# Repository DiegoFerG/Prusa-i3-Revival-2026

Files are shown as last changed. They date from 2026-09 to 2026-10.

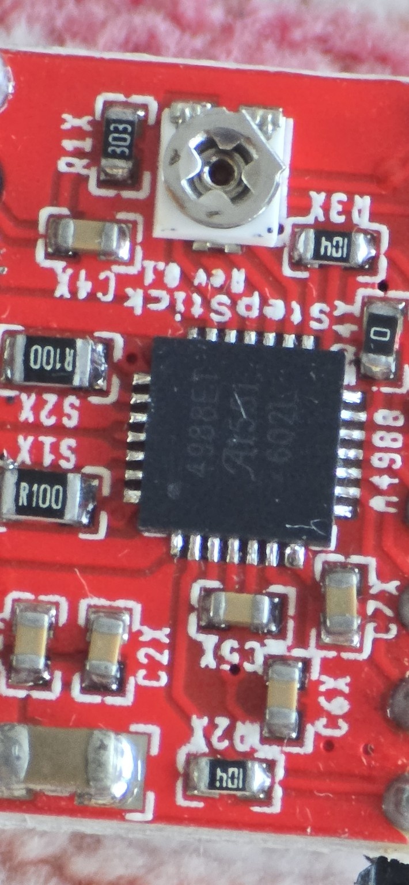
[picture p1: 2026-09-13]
photos/02-teardown/derived/component-inventory/TD-20260913-192-red-a4988-stepper-driver-01.jpg

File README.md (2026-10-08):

# Prusa i3 Revival 2026

> Bringing a classic Prusa i3 back to life — one documented subsystem at a time.

**Prusa i3 Revival 2026** documents the restoration and modernization of a self-built classic Prusa i3 recovered after more than a decade in storage.

The project is not intended to turn the machine into a modern Prusa clone. The objective is to preserve the character and documented history of the original printer while rebuilding it into a safe, reliable and reproducible machine.

## Knowledge base

Open [Home](docs/knowledge-base/Home.md) for project status, decisions, subsystem/build navigation and source-linked evidence indexes. The repository root is also the Obsidian vault. Follow the [maintenance guide](docs/knowledge-base/Maintenance.md) and [repository instructions](AGENTS.md) when changing project knowledge.

## Current status

- **Stage 00 — Archaeology: COMPLETE (12 September 2026).** The non-invasive as-found baseline is frozen and preserved.
- **Stage 01 — Teardown, cleaning and inventory: COMPLETE (13 September 2026).** The printer has been fully dismantled, cleaned and catalogued. The teardown photo sequence reaches `TD-20260913-228`.
- **Stage 02 — Original mechanical reassembly: IN PROGRESS (13 September 2026).** Historical assembly sources have been indexed, a project-specific reassembly manual has been created and physical reconstruction is underway. The Stage 02 photo archive currently contains **116 sanitized JPEGs** in four batches: `RA-20260914-001` through `RA-20260914-035`, `RA-20260915-001` through `RA-20260915-009`, `RA-20260916-001` through `RA-20260916-058`, and `RA-20260921-001` through `RA-20260921-014`. The [16 September batch](photos/03-reassembly/BATCH-20260916.md) records progress through manual Stages B–G. The [21 September batch](photos/03-reassembly/BATCH-20260921.md) adds 14 Stage H photographs of the geared-extruder subassembly. Assembly is reported complete in that batch; mounting and acceptance evidence remain to be recorded. Photographic coverage does not establish completion of every mechanical acceptance check.
- **Generation 3 target architecture: FROZEN (13 September 2026).** The final Manta/CB2/Klipper/CAN architecture is documented in **[docs/final-build-architecture.md](docs/final-build-architecture.md)** and will not be implemented until the earlier generations have been documented and tested. Initial Generation 3 stock has been acquired: Manta M8P V2.0, EBB36 Gen2 kit and 6× BTT TMC2209 V1.3; partial USB communication/sensor/video bench results are now recorded, while full hardware acceptance and printer commissioning remain pending. **[Revival Intelligence & Diagnostics](hardware/generation-3-revival-intelligence-diagnostics.md)** groups future CB2-hosted supervisory intelligence, machine vision, condition monitoring and diagnostic candidate work; individual RID features remain unpromoted until separately evaluated.

The complete stage-by-stage plan is maintained in **[docs/ROADMAP.md](docs/ROADMAP.md)**.

Original printable-design candidates are available in the [historical parts catalogue](printed-parts/original-designs/Original-Printed-Parts.md), including the [small Greg/Wade extruder gear](printed-parts/original-designs/Small-Extruder-Gear.md). The archive preserves source files and provenance; exact part matching and fit checks remain open.

## Confirmed original baseline

The teardown and component inventory established a substantially clearer baseline than the initial visual archaeology:

- classic Prusa i3 / Rework-era / RepRap-derived architecture with a single-sheet steel vertical frame;
- threaded-rod Y structure and 8 mm smooth linear guides;
- Y bed carriage approximately **220 × 220 mm**, approximately **210 mm mounting-hole spacing** in both axes, **6 mm** thick, with M3 threaded mounting holes;
- 2× M10 × 350 mm structural threaded rods, 4× M8 × 200 mm threaded rods and 2× M5 × 310 mm threaded rods;
- 2× Ø8 × 350 mm, 2× Ø8 × 330 mm and 2× Ø8 × 317 mm smooth rods;
- 10× LM8UU-family linear bearings and 3× FAG 608Z radial bearings;
- 5× Wantai **42BYGHW811** NEMA17 motors, labelled **2.5 A** and **1.8°/step**;
- T2.5 belt transmission with approximately 20-tooth aluminium drive pulleys;
- Arduino Mega 2560 + StaticBoards RAMPS 1.4SB + four A4988-family plug-in stepper-driver modules;
- RepRapDiscount-style full graphic controller, RAMPS smart adapter and Panasonic 16 GB SDHC card;
- JCPOWER **JC-360-12** open-frame PSU, **12 V / 30 A**;
- Wade/Greg's-Wade-family geared direct extruder for the legacy 3 mm stage;
- legacy E3D-family hotend, probably V5-era, with exact revision still intentionally unclaimed;
- four IKEA SÖRLI mirrors, **200 × 200 × 3 mm**, used as removable build surfaces;
- screw-and-spring bed levelling hardware, including the historically improvised clothes-peg springs.

The original mixed wiring harness has been documented but **will not be reused**. The revival will be wired from scratch when the electrical stage begins.

## Project generations

The long-term plan deliberately keeps three generations of the same machine visible and documented:

1. **Original Hardware Revival** — rebuild the original machine and establish a reliable legacy 3 mm / 2.85 mm printing baseline using the Arduino Mega 2560 + RAMPS-era stack.
2. **Re-ARM transitional study** — document and, if worthwhile, test the recovered Panucatt Re-ARM with RAMPS-era hardware as a period 32-bit upgrade path.
3. **Revival 2026 final build** — move to 1.75 mm extrusion, 24 V power, modern electronics, CAN toolhead, new wiring and current safety practices while preserving the classic i3 character. The frozen target is defined in **[docs/final-build-architecture.md](docs/final-build-architecture.md)**.

## Design principles

1. **Document before changing.**
2. **Reconstruct before redesigning.**
3. **Reuse only when it makes engineering sense.**
4. **Modernize safety-critical systems.**
5. **Prefer reproducible and readily available components.**
6. **Publish editable source files**, not only STL exports.
7. **Keep the legacy 3 mm stage functional** before the later 1.75 mm conversion.
8. Record measurements, decisions, failures and test results so the work can be reproduced.
9. **Preserve the historical red-and-black visual identity:** mechanical/structural printed parts are red in the final build, while frame and rods remain black; newly introduced enclosures may use other colours/materials when justified by function and design.

## Repository

- `docs/` — archaeology, inventory, roadmap and project documentation
  - [`docs/ROADMAP.md`](docs/ROADMAP.md) — current project stages
  - [`docs/final-build-architecture.md`](docs/final-build-architecture.md) — frozen Generation 3 control/electrical architecture and final visual identity
  - `docs/00-archaeology/` — frozen as-found archaeology and provenance
  - `docs/01-filaments/` — recovered legacy-filament inventory and future qualification
  - [`docs/02-reassembly/`](docs/02-reassembly/) — Stage 02 historical source index and original-geometry reassembly manual
- `hardware/` — mechanical/electrical baseline and future BOM documentation
- `printed-parts/` — CAD sources, STEP, STL and reference 3MF projects
- `firmware/` — printer configurations for the documented generations
- `profiles/` — manufacturing and slicer profiles
- `photos/00-archaeology/` — frozen Stage 00 evidence
- `photos/02-teardown/` — Stage 01 teardown originals and cleaned component-inventory derivatives (`TD-20260913-001` through `TD-20260913-228`)
- [`photos/03-reassembly/`](photos/03-reassembly/) — Stage 02 sanitized reassembly evidence: **116 photographs** across `RA-20260914-001`–`035`, `RA-20260915-001`–`009`, `RA-20260916-001`–`058` and `RA-20260921-001`–`014`

## Safety

No old mains-powered hardware should be energized merely to see whether it still works. The PSU, mains wiring, heated bed, connectors, power distribution, insulation and protection arrangements must be inspected before electrical commissioning.

---

Started in September 2026.

## Latest electronics bench — 8 October 2026

[Session record](hardware/bench-tests/generation-3-electronics/records/2026-10-08-usb-eddy-camera.md): CB1 on the replacement Manta, EBB36 Gen2, Eddy Duo and main camera. Corrected short cable enables Eddy USB through EBB; direct-USB 30-minute acquisition passed; camera video and reboot/cold start worked. Joint prolonged USB validation, distance calibration, direct CAN and later CEB CAN remain pending. This separate bench does not change original reassembly completion.

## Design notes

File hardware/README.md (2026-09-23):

# Hardware baseline

This directory is the home for mechanical/electrical documentation, schematics and future bills of materials for **Prusa i3 Revival 2026**.

The Stage 01 teardown and physical inventory was completed on **13 September 2026**. The table below records the current original-hardware baseline before reassembly and modernization.

## Mechanical inventory

| Item | Quantity / measurement | Current identification / status |
|---|---|---|
| Main vertical frame | 1 | Single-sheet steel frame from a classic Prusa i3 / Rework-era / RepRap-derived machine; detailed measurement photos exist in `TD-160…170` |
| Y bed carriage/support | 1 | approximately 220 × 220 mm; approximately 210 mm hole spacing horizontally and vertically; approximately 6 mm thick; M3 threaded mounting holes |
| Structural threaded rods | 2 | M10 × 350 mm |
| Structural threaded rods | 4 | M8 × 200 mm |
| Z threaded rods | 2 | M5 × 310 mm; original conventional threaded-rod drive |
| Smooth rods | 2 | Ø8 × 350 mm; probable Y pair |
| Smooth rods | 2 | Ø8 × 330 mm; probable Z pair |
| Smooth rods | 2 | Ø8 × 317 mm; probable X pair |
| Linear bearings | 10 | LM8UU-family, approximately 8 mm bore × 15 mm OD × 24 mm long |
| Radial bearings | 3 | FAG 608Z, 8 × 22 × 7 mm family |
| Z flexible couplers | 2 | Aluminium helical couplers; bore dimensions still to be confirmed before reuse |
| Drive pulleys | 2 | Aluminium T2.5-compatible, approximately 20 teeth and approximately 15 mm outside diameter |
| Open timing belt | 1 documented loose belt | approximately 800 mm, T2.5 trapezoidal profile |
| Bed/build surfaces | 4 | IKEA SÖRLI mirrors, 200 × 200 × 3 mm; one original label preserved |
| Bed levelling hardware | mixed | Long screws, washers and springs; the characteristic springs were repurposed from clothes pegs |
| Fasteners | mixed lots | Screws, nuts, washers and spacers intentionally not individually counted |

## Motors

**5× Wantai 42BYGHW811 NEMA17** motors were recovered from the printer and catalogued as the same model.

Visible label data:

- 1.8° per step;
- 2.5 A current marking.

Electrical condition, winding resistance and bearing condition still need controlled testing before any reuse decision.

## Original electronics

| Item | Quantity | Identification / status |
|---|---:|---|
| Main controller | 1 | Arduino Mega 2560 |
| Motion/power shield | 1 | StaticBoards RAMPS 1.4SB |
| Stepper modules | 4 | A4988-family plug-in drivers; exact clone/revision not fully proven |
| Graphic controller | 1 | RepRapDiscount-style full graphic smart controller |
| LCD adapter | 1 | RAMPS smart adapter, EXP1/EXP2 style |
| SD card | 1 | Panasonic SDHC, 16 GB; contents not yet treated as trusted/project documentation |
| PSU | 1 | JCPOWER JC-360-12, 110/220 VAC ±15% input, 12 V / 30 A output, open-frame fan-cooled unit |
| Endstops | several original modules | Mechanical switch modules documented in teardown photos `TD-147…154`; individual electrical testing pending |

The old mixed wiring harness was photographed and archived but **will not be reused**. Stage 05 will design and build new wiring from scratch.

## Extrusion system

### Geared extruder

The original carriage uses a direct geared extruder from the **Wade / Greg's Wade family**, compatible with the machine's legacy 3 mm / 2.85 mm filament stage.

### Hotend

Current identification: **legacy E3D-family, probable V5-era**, groove-mount style, for the original large-diameter filament system.

Documented parts include:

- aluminium heatsink;
- threaded heatbreak / hot-side connection;
- heater block;
- installed heater cartridge;
- separate bead thermistor and wiring.

The exact E3D revision is intentionally not claimed yet. The heater cartridge is currently captive because the retaining screw head in the heater block is stripped. It was deliberately left in place rather than damaging the block during inventory.

The thermistor is probably a common 100 kΩ NTC type for the period, but this remains **unconfirmed** until its room-temperature resistance and response are measured.

## Heated bed

The original heated-bed PCB is documented in the Stage 01 original teardown archive, including close-ups around `TD-138…141`. Electrical resistance, flatness, insulation and wiring condition must be checked before power testing.

## Reassembly policy

Stage 02 will first reconstruct the original mechanical machine using the evidence in `photos/02-teardown/`.

During reassembly each component should be classified as needed:

- **REUSE** — acceptable as-is after inspection;
- **RESTORE** — clean/lubricate/repair, then reassess;
- **REPLACE** — functionally equivalent replacement required;
- **REDESIGN** — intentionally changed for the Revival;
- **ARCHIVE** — retained primarily as historical evidence.

Modernization ideas should be recorded during Stage 02, but the original geometry should be understood before it is altered.

## Electrical safety

No mains-powered component is cleared for use merely because it looks intact. The JCPOWER PSU, heated bed, RAMPS power stage, connectors and all mains-side arrangements require separate electrical/safety inspection before commissioning.

## Generation 3 vendor reference documentation

Official BIGTREETECH manuals, pinouts, schematics, connection diagrams, reference Klipper configurations and self-contained wiki snapshots for the purchased Manta M8P V2.0, EBB36 Gen2 / USB adapter and TMC2209 V1.3 are preserved in the [BIGTREETECH vendor reference archive](reference/bigtreetech/README.md).

These are pinned third-party references. They do not change any component from purchased to tested or commissioned.

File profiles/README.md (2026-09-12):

# Profiles

Manufacturing profiles for Revival parts and slicer profiles for the rebuilt printer itself.

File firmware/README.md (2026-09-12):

# Firmware

Configurations for the Legacy 3 mm stage and the future 1.75 mm conversion.

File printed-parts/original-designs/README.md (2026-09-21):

---
type: archive
area: mechanics
status: under-study
phase: stage-02
generation: original
updated: 2026-09-19
---

# Original design archive

Local copies of historical Prusa i3 single-sheet and Greg/Wade designs, recovered on 19 September 2026. Start with the [original printed-parts catalogue](Original-Printed-Parts.md), or go directly to the [small extruder gear](Small-Extruder-Gear.md).

The archive contains **62 unchanged upstream files: 23 STL files, 31 SCAD files, two configuration templates and six documentation/build files**, approximately 7.64 MB. STL count includes alternative versions and plates containing multiple objects; it is not a count of installed parts.

These are authentic published designs, not yet a fully verified set of exact replacements for this individual printer. The supplier and exact kit revision are unknown. The catalogue records the strongest matches, alternatives and remaining gaps. No reprint, fit test or new assembly completion is implied.

| Collection | Contents | Use |
| --- | --- | --- |
| [Original printed parts](Original-Printed-Parts.md) | Links by assembly role and phase | Find a part without searching filenames |
| [Small extruder gear](Small-Extruder-Gear.md) | Direct STL link, matching gear and inspection checklist | Prepare the Stage H replacement in Bambu Studio |
| [Provenance and licenses](Provenance.md) | Authors, pinned revisions, retrieval, exclusions and license notices | Distinguish original files from later project work |
| [Manifest](manifest.json) | Source path, byte count and SHA-256 for every imported file | Check archive integrity |
| [Verification tool](verify_archive.py) | Standard-library Python archive and STL checks | Recheck after copying or updating the archive |

## Preservation and future changes

Keep `upstream/` byte-for-byte unchanged, including original filenames and notices. Do not repair, rescale or overwrite an upstream STL. Store a modified replacement in a separate project design directory with its parent file/hash, changes, dimensions and print/fit results. Update this catalogue and the affected knowledge-base pages in the same change.

The original SCAD configuration templates must be copied and deliberately configured in a **separate working copy** before compilation. They are not P1S printer profiles. The old single-plate template uses T2.5; the separate `box_frame` template has other defaults and must be checked before generating endstop holders. See [provenance](Provenance.md#editable-sources-and-dependencies).

[Printed parts](../README.md) · [Parts index](../../docs/knowledge-base/indexes/Parts.md) · [Stage 02](../../docs/knowledge-base/build/Stage-02-Original-Reassembly.md)

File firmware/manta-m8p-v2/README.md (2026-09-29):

# Manta M8P V2 Firmware

Firmware and host configuration for the Generation 3 electronics of
Prusa i3 Revival 2026 (PHOENIX).

## Architecture

PHOENIX uses a BIGTREETECH Manta M8P V2 as the main controller.

Host computer:
- Temporary bring-up: BIGTREETECH CB1
- Final target: BIGTREETECH CB2 or Raspberry Pi CM4
- Current CB1 hostname: PHOENIX-CB1

Toolhead:
- BIGTREETECH EBB36
- CAN/USB architecture to be finalized during commissioning.

## Directories

- host/    Host/SBC configuration and installation documentation.
- mcu/     Manta STM32H723 firmware build and flashing documentation.
- klipper/ Version-controlled Klipper configuration for PHOENIX.

## Security

Real system.cfg files and other files containing credentials must never
be committed. Use the sanitized templates stored in this repository.

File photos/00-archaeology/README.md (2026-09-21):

# Archaeology photo archive

This directory contains the photographic evidence collected during **Stage 00 — Archaeology** of Prusa i3 Revival 2026.

## Originals

`originals/` currently contains **89 JPEG files**, with two distinct provenance groups:

- **80 historical baseline photographs**, ARQ 001–080, captured during the archaeology work on 12–13 September 2026 and committed without intentional image editing or recompression. This remains the frozen baseline.
- **Nine later spare-box photographs**, `ARQ-20260915-081`–`ARQ-20260915-089`, published after metadata sanitization. Their legacy `originals/` location does not make them untouched camera originals. The [spare-box record](../../docs/00-archaeology/06-motion-electronics-spares.md) records their recovery and processing.

This summary was reconciled with the [current photo catalogue](../../docs/00-archaeology/02-photo-catalogue.md) and repository files on 21 September 2026. No evidence files or permanent IDs were changed.

Their filenames use the legacy permanent identifier format:

`ARQ-YYYYMMDD-NNN-<capture-or-source-id>.jpg`

`ARQ` is retained as an opaque historical ID prefix because these identifiers were already established as the canonical evidence references. All descriptive repository paths, document names and new filenames are standardised in English.

## Evidence classes

The archive intentionally mixes several kinds of discoveries made during the archaeology sessions. A photograph does **not** prove that the pictured object was installed on the printer.

- **PRINTER-AS-FOUND** — component visibly installed on the printer before dismantling.
- **LOOSE-FOUND** — loose component found in boxes from the same period.
- **DONATED-PURCHASED** — component known to have been donated or purchased at the time.
- **PERIOD-UNRELATED** — period hardware not known to belong to the printer, but retained as technological context.
- **UNKNOWN** — provenance or function still unresolved.

## Preservation policy

Do not edit, overwrite, rotate destructively or recompress files in `originals/`. Crops, annotations, web versions and comparison images belong in `derived/`.

## Documentation

See:
- [Archaeology documentation](../../docs/00-archaeology/README.md)
- [Photo catalogue](../../docs/00-archaeology/02-photo-catalogue.md)
- [Evidence rules](../../docs/00-archaeology/03-method-and-provenance.md)
- [Blog source notes](../../docs/00-archaeology/04-blog-source-notes-chapter-0.md)

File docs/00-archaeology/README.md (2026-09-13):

# 00 — Archaeology

This stage documents the machine **before cleaning, dismantling or replacing components**.

## Status

**CLOSED — 12 September 2026.**

Stage 00 remains a frozen non-invasive baseline. At the moment this stage closed, the printer had not yet been dismantled; that statement is historical context, not the current project state.

**Downstream update:** Stage 01 teardown, cleaning and component inventory was completed on **13 September 2026**. The printer is now dismantled and catalogued, and the next project step is original mechanical reassembly. Technical identifications resolved during teardown belong to Stage 01 and are cross-referenced rather than retroactively rewritten into the as-found evidence.

## Objectives achieved

- Photograph the complete machine and major subsystems before dismantling.
- Inventory loose recovered parts separately from installed hardware.
- Preserve provenance and confidence levels.
- Avoid powering uninspected electrical hardware.
- Create a traceable source for the technical documentation and bilingual blog.

## Frozen evidence

A set of **80 original ARQ photographs** is preserved at:

`photos/00-archaeology/originals/`

The archive includes both printer-as-found evidence and loose period material. Loose material is never assumed to have been part of the printer without evidence.

## What later teardown resolved

Stage 01 subsequently confirmed, among other things:

- Arduino Mega 2560 + StaticBoards RAMPS 1.4SB installed controller stack;
- 4× A4988-family plug-in driver modules;
- 5× Wantai 42BYGHW811 NEMA17 motors;
- JCPOWER JC-360-12, 12 V / 30 A PSU;
- measured rod and Y-carriage dimensions;
- T2.5 belt transmission;
- LM8UU-family linear bearings and FAG 608Z radial bearings;
- four IKEA SÖRLI 200 × 200 × 3 mm build-surface mirrors;
- legacy E3D-family hotend and thermistor assembly.

See [Stage 01 teardown photos](../../photos/02-teardown/README.md) and the [hardware baseline](../../hardware/README.md).

## Documents in this stage

- [01 — Initial inventory](01-initial-inventory.md)
- [02 — Photo catalogue](02-photo-catalogue.md)
- [03 — Archaeology method and provenance](03-method-and-provenance.md)
- [04 — Blog source notes / Chapter 0](04-blog-source-notes-chapter-0.md)
- [05 — Detailed ARQ photo inventory](05-detailed-photo-inventory.md)
- [Photo archive](../../photos/00-archaeology/README.md)

## Critical distinction

The project maintains separate evidence classes for:

1. components physically installed on the printer;
2. items found loose in boxes from the same period;
3. donated/purchased period material;
4. unrelated period hardware;
5. Revival-2026 additions.

A motor, board or printed part found near the Prusa is not considered part of its original configuration unless evidence demonstrates that relationship.

## Archaeology closure rule

Stage 00 IDs and original images remain stable. Later evidence may refine an identification, but it does not alter the fact that the earlier observation was provisional at the time.

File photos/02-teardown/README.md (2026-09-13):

# Stage 01 — Teardown, cleaning and inventory photo archive

This directory contains the photographic evidence collected during **Stage 01 — Teardown, cleaning and inventory** of Prusa i3 Revival 2026.

**Stage status: COMPLETE — 13 September 2026.**

The current chronological `TD-` sequence runs from `TD-20260913-001` through `TD-20260913-228`.

## Originals

`originals/` contains **159 immutable evidence photographs**:

- `001–040`: workbench preparation, complete-printer baseline and installed subsystem close-ups;
- `041–159`: controlled teardown, removed components, wiring, electronics, printed parts and final disassembled state.

Original evidence files must not be intentionally edited, overwritten, destructively rotated or recompressed.

## Derived component inventory

`derived/component-inventory/` contains **69 cleaned catalogue photographs**, `160–228`.

These are intentionally **derivatives**, not forensic originals. Each JPEG was decoded, orientation-corrected and re-encoded from pixel data without retaining EXIF, GPS, XMP or camera/device metadata. No generative or content-changing edit was applied.

The derived inventory documents measured frame/carriage geometry, rods, motors, mirrors, electronics, PSU, motion hardware, bearings, hotend and thermistor.

## Naming convention

`TD-YYYYMMDD-NNN-subsystem-description.jpg`

Where:

- `TD` = Teardown;
- `YYYYMMDD` = capture/inventory date;
- `NNN` = stable chronological identifier within the Stage 01 archive;
- `subsystem-description` = concise English description.

## Indexes and manifests

- [INDEX.md](INDEX.md) — Stage 01 range/index overview;
- `manifest.csv` — originals `001–040`;
- `inventory-20260913.csv` — originals `041–159`;
- [BATCH-20260913.md](BATCH-20260913.md) — batch history and counts;
- `derived/component-inventory/manifest.csv` — derivatives `160–228`;
- `derived/component-inventory/SHA256SUMS.txt` — derivative integrity hashes.

## Language and path convention

Repository directory names, filenames, document filenames and repository documentation use **English**. Public blog content may be bilingual as defined by the roadmap.

## Next stage

Stage 02 will use this archive to reconstruct the printer's original mechanical geometry before modernization. Reassembly evidence should be stored as a new stage/batch rather than changing Stage 01 originals.

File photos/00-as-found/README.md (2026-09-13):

# As found — 2026-09-12

Initial photographs taken while the printer was still in storage, before cleaning, moving or dismantling.

The original files are preserved without editing as evidence of the machine's initial condition.

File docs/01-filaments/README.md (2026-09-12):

# Legacy filament archive

This folder documents the surviving legacy filament stock recovered for **Prusa i3 Revival 2026**.

The project deliberately keeps a functional **3 mm / 2.85 mm extrusion stage** so this material can be evaluated and, where practical, consumed before the later conversion to 1.75 mm.

## Rules

- Photograph and catalogue every spool/box before use.
- Record the nominal diameter exactly as labelled: legacy "3.00 mm" and modern 2.85 mm are not assumed identical.
- Dry and test old filament before committing to long prints.
- Never infer material from colour alone.
- Record failures as well as successful settings.
- Abrasive or filled materials require a suitable nozzle.
- Filament that is brittle, chemically degraded or dimensionally inconsistent may be retained for documentation rather than printed.

## Current batch

The first filament archaeology batch contains FFF World / Smart Materials products in ABS-family, PLA-family and flexible TPU-family materials.

See [01-inventory.md](01-inventory.md) for the current inventory and reuse assessment.

## Photo archive

Batch 01 is now complete: **11/11 photographs uploaded** to:

`photos/01-filaments/originals/`

Every image is cross-referenced from [01-inventory.md](01-inventory.md), which also contains the per-photo catalogue.

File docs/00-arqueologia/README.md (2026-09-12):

# 00 — Archaeology

This stage documents the machine **before cleaning, dismantling, or replacing components**.

## Objectives

- Identify the exact Prusa i3 variant.
- Photograph the complete machine and each subsystem.
- Inventory loose recovered parts separately.
- Measure the frame, rods, bearings, fasteners, bed and transmissions during teardown.
- Identify the extruder, hotend, motors, power supply, controller and endstops.
- Classify each component as reuse, restore, replace, redesign or archive.
- Do not power the old electronics before an electrical inspection.
- Preserve enough traceability to turn this stage into both technical documentation and Chapter 0 of the bilingual blog.

## Current status

**CLOSED — 12 September 2026.**

The initial non-invasive archaeology session is now frozen as the project's pre-teardown baseline. The printer has **not yet been dismantled**. From this point onward, observations made while removing components belong to the teardown/assessment stage rather than being retroactively folded into the as-found archaeology.

A set of **72 original photographs** is preserved at:

`photos/00-arqueologia/originals/`

The second archaeology batch also documents loose period electronics, notably a **Panucatt Devices Re-ARM** paired with a **RAMPS 1.4sb**, plus LCDs, Arduino-class boards, heater cartridges, heatsinks, an Ethernet module and assorted fans. Their relationship to the printer is not assumed and their electrical condition is still untested.

The provisional identification points to a classic/Rework-era Prusa i3 / RepRap derivative with a Wade/Greg's-Wade-family geared extruder and an E3D-family hotend. The exact printer variant and several component revisions remain open until teardown and measurement.

## Documents in this stage

- [01 — Initial inventory](01-primer-inventario.md)
- [02 — Photo catalogue](02-catalogo-fotografico.md)
- [03 — Archaeology method and provenance](03-metodologia-y-procedencia.md)
- [04 — Blog source notes / Chapter 0](04-notas-blog-capitulo-0.md)
- [05 — Detailed photo inventory (72 files)](05-detailed-photo-inventory.md)
- [Photo archive](../../photos/00-arqueologia/README.md)

## Critical distinction

The project maintains two different kinds of evidence:

1. **Components physically installed on the printer.**
2. **Items found loose in boxes from the same period.**

A motor, board or printed part found near the Prusa is not considered part of its original configuration unless evidence demonstrates that relationship.

## Archaeology closure

The as-found evidence set is considered sufficient to begin controlled teardown. Open questions are intentionally carried forward instead of being guessed.

During teardown, follow the documented workflow:

photograph → ID → connections/orientation → removal → cleaning → measurements → test → decision → record

New close-up photographs may clarify an existing ARQ identification, but teardown evidence must be documented as a new stage/batch so the original baseline remains immutable.

## Blog workflow

The blog is a **living project log**, not a final retrospective deliverable. Archaeology provides the source material for the first article/chapter, and every later project stage should update the Spanish and English blog as work actually happens. Technical conclusions in the blog should link back to repository evidence whenever practical.

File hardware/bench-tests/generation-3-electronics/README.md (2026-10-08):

# Generation 3 electronics bench-test pack

Version: **1.0**  
Prepared: **22 September 2026**

## Purpose

Validate the purchased Generation 3 electronics while return/warranty windows are still open:

- 1 × BIGTREETECH Manta M8P V2.0
- 6 × BIGTREETECH TMC2209 V1.3
- 1 × BIGTREETECH EBB36 Gen2 kit including the Gen2 adapter/protection board

The original pack proposed a Raspberry Pi 2 as a temporary host. The active 8 October 2026 bench uses **CB1 mounted on Manta**, as recorded below. This does not change CB2 as the frozen final Generation 3 host.

## Acceptance rule

A component may be marked **TESTED / PASS** only after:

1. packaging and exact PCB revision are photographed;
2. visual inspection finds no disqualifying damage;
3. power-up shows no abnormal smell, heat or current draw;
4. communication with Klipper is stable;
5. the applicable functional tests pass;
6. evidence is retained in the test record.

`Purchased != Tested != Commissioned`.

## Test order

1. [Materials and safety](00-materials-and-safety.md)
2. [Receiving inspection](01-receiving-inspection.md)
3. [Raspberry Pi 2 Klipper host](02-rpi2-klipper-host.md)
4. [Manta USB smoke test](03-manta-usb-smoke-test.md)
5. [Test all six TMC2209 modules](04-test-six-tmc2209.md)
6. [Test all eight Manta driver sockets](05-test-eight-manta-sockets.md)
7. [EBB36 Gen2 USB test](06-ebb36-usb.md)
8. [Manta ↔ EBB36 CAN test](07-manta-ebb36-can.md)
9. [Optional low-risk I/O tests](08-optional-io-tests.md)
10. [Closeout and evidence](09-closeout-and-evidence.md)

Bench configurations are intentionally conservative and are **not final printer settings**.

## Bench fixture

Before CAD, use the [bench-fixture dimensional survey](bench-fixture-dimensional-survey.md) to record the exact mounting, connector and service-clearance geometry of the Manta, temporary Raspberry Pi 2, 24 V bench power supply and EBB USB Adapter.

## Records

- [Acceptance register](records/acceptance.csv)
- [Test notes](records/test-notes.md)
- [Sources](SOURCES.md)

Future evidence should be added with clear dates and component IDs. Photographs remain evidence, not proof of a passed test unless linked to a recorded result.

## Active bench — 8 October 2026

See the [USB Eddy and camera session record](records/2026-10-08-usb-eddy-camera.md) for the current wiring, cable correction, MCU/configuration snapshot, measurements, failures and recovery. USB direct baseline capture passed; USB through EBB communicates and camera video/reboot/cold start worked. Joint 30-minute stability remains pending. Next transport order is **USB → direct CAN without CEB → CAN through CEB**. CEB remains to order. This does not close motor/heater/full-board acceptance.

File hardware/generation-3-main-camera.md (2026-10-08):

# Generation 3 main frame camera

## Frozen selection

The Generation 3 primary frame camera is the **Innomaker U30CAM-4K-S1** USB UVC camera module.

This selection supersedes the earlier CSI-first / model-open camera concept. Those references are obsolete for the primary frame camera. CSI may still be evaluated for unrelated future imaging experiments, but it is no longer the baseline for the main camera.

### Identification

- Manufacturer: Innomaker
- Model: **U30CAM-4K-S1**
- Amazon ES ASIN: **B0FQJB4Z79**
- Sensor: **Sony IMX415 STARVIS**, approximately 8 MP
- Host interface: **USB 3.0, UVC**, with USB 2.0 backward compatibility
- Advertised primary video modes: **3840 × 2160 at 30 fps** and **1920 × 1080 at 60 fps**
- Advertised formats include **MJPEG** and **YUY2**
- Lens: wide-angle, adjustable focus
- Approximate field of view: **105° horizontal / 116° diagonal**
- Approximate PCB size: **38 × 38 mm**

The exact modes, frame rates, pixel formats and controls exposed by the delivered unit are not treated as bench-verified until queried with V4L2.

## Host compatibility and migration

The camera is deliberately USB/UVC so the same main camera can survive Linux-host changes without depending on a CSI sensor driver or device-tree overlay.

Planned host progression:

1. **CB1 bench stage:** connect as a standard Linux UVC camera. Start validation at 1920 × 1080 MJPEG / 30 fps, then test 60 fps and higher modes while observing host load, temperature, latency and Klipper stability.
2. **CB2 final target:** retain the same UVC camera; use the best validated USB path and reassess 4K30 / 1080p60 operation.
3. **CM4 alternative:** retain UVC compatibility if CM4 is selected instead of CB2; achievable high-rate modes remain dependent on the actual USB topology and compressed format.

A mode being advertised by the camera does not by itself prove that a given host/topology can sustain it reliably.

## Mechanical integration

The camera remains **fixed to the printer frame**, never to the moving bed or toolhead.

Requirements:

- stable view of the complete bed/nozzle work area;
- exploit the wide-angle lens while avoiding unnecessary distortion of the useful print region;
- adjustable mount for final framing and focus;
- custom ASA enclosure with late-1980s/1990s industrial CCTV/video-surveillance language;
- no exposed modern PCB in the finished machine;
- preserve access to focus adjustment and USB service connection;
- final mount geometry is frozen only after physical framing tests on the rebuilt printer.

## Software and RID role

The main camera is a first-class input for Crowsnest/Mainsail and for **Revival Intelligence & Diagnostics (RID)**.

Normal operation should favour a resolution/frame-rate combination that leaves comfortable host margin. 4K is valuable for detailed captures, timelapse and vision regions of interest; continuous 4K operation is not a requirement.

RID may reuse the stream or selected frames for print-failure detection, first-layer inspection, anomaly evidence, fiducial/geometry checks and later vision candidates. Deterministic printer control and safety remain independent of camera/RID availability.

## Incoming bench acceptance

On receipt, record the real device rather than relying only on seller specifications:

```bash
lsusb
lsusb -t
v4l2-ctl --list-devices
v4l2-ctl --list-formats-ext -d /dev/video0
```

Then validate at minimum:

- enumeration and stable reconnect on the CB1;
- UVC/V4L2 operation;
- actual MJPEG/YUY2 mode table;
- 1080p30 baseline;
- 1080p60 if exposed;
- 4K30 if exposed, noting USB topology and host load;
- Crowsnest/Mainsail stream;
- sustained CPU load, temperature and Klipper stability;
- focus range and useful frame coverage at plausible mounting distances.

## Superseded camera assumptions

The following previous assumptions are explicitly obsolete for the **main frame camera**:

- “CSI preferred, USB permitted”;
- “camera model/interface open”;
- “select CSI first and fall back to USB if ribbon routing is difficult”;
- deferring the main sensor/lens/interface selection entirely until later framing tests.

Physical mount position and final framing remain open until the delivered U30CAM-4K-S1 is tested on the machine.

## Delivered-unit bench results — 8 October 2026

The [session record](bench-tests/generation-3-electronics/records/2026-10-08-usb-eddy-camera.md) confirms receipt, UVC detection (0bda:5883), real MJPEG/YUYV mode queries and visible Crowsnest/Mainsail video on CB1. Initial validation was deliberately lowered to **640x480**, not the previously planned 1080p baseline. A 30-second MJPEG copy test acquired 30 fps; Mainsail later displayed 15 FPS with max_fps:15. Higher modes remain untested. Focus controls produced UVC non-compliance errors; physical focus/framing remains open.

Use /webcam/?action=stream and /webcam/?action=snapshot through the Mainsail web proxy. Port 8080 listens on loopback only. Initial camera hot-plug disconnected the EBB/Eddy USB branch; firmware restart recovered Klipper. Later warm reboot and PSU cold start worked with the camera attached. Cause of the initial disruption remains unproven; prolonged concurrent validation is pending.

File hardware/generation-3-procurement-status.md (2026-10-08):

# Generation 3 procurement status

This document tracks **actual Generation 3 purchases and near-term acquisition decisions** separately from the target BOM.

It must not be used as evidence that a purchased component has been electrically tested, installed or commissioned.

Last reviewed: **8 October 2026**.

## Purchased

| Component | Quantity | Purchase state | Intended Generation 3 role |
|---|---:|---|---|
| BIGTREETECH Manta M8P V2.0 | 1 | Purchased | Main motion/control MCU board |
| BIGTREETECH EBB36 Gen2 | 1 kit | Purchased | CAN toolhead MCU/driver board; kit includes its Gen2 adapter/protection board |
| BIGTREETECH TMC2209 V1.3 | 6 | Purchased | Manta axis drivers plus spares |
| BIGTREETECH CB1 | 1 | Received; active temporary bench host | Mounted on Manta; final CB2 target unchanged |
| BIGTREETECH Eddy Duo | 1 | Received; USB communication and raw sensor acquisition tested | Probe/scanner; final mount/calibration/CAN pending |
| Innomaker U30CAM-4K-S1 | 1 | Received; UVC and Mainsail video tested | Main frame camera; sustained/higher-mode testing pending |

### TMC2209 allocation

The base Generation 3 machine does **not** require eight populated Manta driver sockets.

Expected base allocation:

- X;
- Y;
- Z0;
- Z1.

The E3D Roto extruder is driven by the **TMC2209 integrated on the EBB36 Gen2**, not by a Manta socket.

Therefore the six purchased plug-in TMC2209 modules provide:

- four expected base axis drivers;
- two immediate spares / future expansion modules.

Additional Manta drivers should only be purchased if a later subsystem actually requires them.

## Existing prototype stock

### RASS prototype parts already on hand

| Component | Quantity | Status | Intended test |
|---|---:|---|---|
| 28BYJ-48 5 V geared stepper | at least 1 observed | Existing part; untested for RASS | Candidate spool-drive motor only |
| ULN2003 5 V stepper driver board | at least 1 observed | Existing part; untested for RASS | Early standalone spool-drive bench prototype only; not the production CAN-node driver |

These parts are **not** frozen production selections and are **not** candidates for the precision filament feeder. They are retained as the preferred no-cost prototype for active spool rotation and must be tested with a full spool and the final load-cell/roller concept.

## Frozen but not yet purchased

| Component | State | Procurement note |
|---|---|---|
| BIGTREETECH CB2 | Frozen host choice | Wait for a reasonable price/availability; do not buy a CM4 merely because CB2 is temporarily harder to source |
| E3D Roto + Revo | Frozen extrusion architecture | Current purchase preference is **Roto Sensored + Revo 24 V / 40 W**; exact retail bundle/SKU to confirm at purchase |
| BIGTREETECH CEB V1.0 | Frozen CAN backbone/distribution for EBB36/Eddy, Revival Bed Node and RASS CAN Node | Not yet purchased |
| Custom Revival RASS CAN Node | Frozen production controller architecture | Custom PCB to design; Klipper-compatible CAN MCU, exact MCU/transceiver/drivers open |
| BIGTREETECH HDMI5 | Frozen local display | Not yet purchased |
| BIGTREETECH S2DW V1.0 | Transitional USB bed accelerometer for commissioning/bench work before the custom Bed Node | Not yet purchased |
| Mean Well LRS-600-24 | Preferred final PSU | 24 V / 25 A / 600 W; future purchase; Amazon Spain reference: https://www.amazon.es/dp/B0D173X5V3 |

## Existing 24 V PSU for prototype use

An existing **NUOFUWEI S-24-600, 24 V / 25 A / 600 W** supply can be recovered from a previous project and may be used for bench/prototype work after inspection and electrical validation.

It is **not** the preferred final PSU. The final-machine target is the Mean Well LRS-600-24 above.

## Host decision: CB2 versus CM4

The frozen final host remains **BIGTREETECH CB2**.

A Raspberry Pi CM4 is technically viable on the Manta M8P V2.0 and remains a fallback/alternative, but the project will not pay a large premium solely for current Amazon availability.

Current procurement rule:

> Wait for a sensibly priced CB2 unless a later engineering reason justifies switching the frozen host architecture.

CM5 is not the target host.

## Bench-test pack

A versioned acceptance-test pack for the purchased Manta M8P V2.0, six TMC2209 V1.3 modules and EBB36 Gen2 kit is stored at [`bench-tests/generation-3-electronics/`](bench-tests/generation-3-electronics/README.md).

The pack defines receiving inspection, Raspberry Pi 2 temporary-host setup, conservative driver tests, all-eight-socket Manta coverage, EBB36 USB validation and a two-node Manta/EBB36 CAN test. It also provides an acceptance CSV and evidence-capture scripts.

**The existence of the test pack does not change any component to Tested.** That status requires reviewed evidence and a recorded PASS.

## Manta bench testing before CB2 purchase

The Manta M8P V2.0 can be checked before the CB2 arrives.

A temporary Linux host can run Klipper and communicate with the Manta over USB:

```text
temporary Linux PC / Raspberry Pi
              |
             USB
              |
        Manta M8P V2.0
```

This permits staged verification of:

- board power-up;
- USB/MCU communication;
- firmware flashing/DFU workflow;
- Klipper MCU connection;
- TMC2209 detection after drivers are fitted;
- endstop/input tests;
- low-risk fan/output tests;
- later CAN testing once a second CAN node is available.

The final integrated CAN architecture is:

```text
CB2 / Klipper host
       |
Manta M8P V2.0
       |
      CAN
       |
BIGTREETECH CEB V1.0
       |
       +-- EBB36 Gen2
       |      |
       |      +-- CAN passthrough -> Eddy Duo
       |
       +-- Revival Bed Node
       |      |
       |      +-- USB-C service / recovery / optional alternate runtime
       |
       +-- Custom RASS CAN Node
              |
              +-- feeder / spool assist / buffer / encoder sensing
```

The CEB is the Generation 3 CAN backbone/distribution point. Bed-heater power remains on its own dedicated fused 24 V high-current path and is not routed through the CEB.

## Frozen toolhead purchase direction

The Generation 3 toolhead stack is frozen as:

- BIGTREETECH EBB36 Gen2;
- E3D Roto;
- E3D Revo;
- BIGTREETECH Eddy Duo.

Current purchase preference:

- **Roto Sensored** rather than Standard;
- **Revo 24 V / 40 W** rather than 60 W for the quality-first PLA use case;
- 0.4 mm Revo nozzle as the normal starting nozzle.

Roto Sensored and the 40 W HeaterCore are procurement preferences within the frozen Roto/Revo architecture. They should be re-checked against the exact product revision available at purchase time.

## Eddy Duo electrical topology

The intended toolhead bus topology is:

```text
Manta / CEB
   |
   | 24 V + GND + CAN-H + CAN-L
   v
EBB36 Gen2 + Gen2 adapter/protection board
   |
   | CAN passthrough + regulated 5 V + GND
   v
Eddy Duo
```

Key rules:

- EBB36 receives the main toolhead 24 V supply.
- Eddy Duo must **not** be fed with 24 V.
- Eddy Duo is supplied at **5 V** and is treated as its own CAN MCU/node.
- Eddy Duo is not configured as an I2C peripheral of the EBB36; that topology applies to an Eddy Coil-class sensor, not the Duo.
- If Eddy Duo is the physical end of the CAN bus, termination is enabled at the bus ends only; the intermediate EBB36 termination must remain disabled.
- Exact connector pinout and harness implementation must be verified against the hardware revision in hand before wiring.

## Receiving inspection rule

Every Generation 3 purchase should be tested while return/warranty windows are still open.

Minimum process:

1. photograph packaging, labels and PCB revision;
2. record supplier/date;
3. inspect for transport damage;
4. verify the exact revision against the canonical architecture;
5. perform a low-risk bench test before long-term storage;
6. update this procurement file and the Obsidian knowledge base;
7. only then mark the component as **tested**.

Purchased is not the same as tested, and tested is not the same as commissioned.

## Partial test evidence — 8 October 2026

[USB bench session](bench-tests/generation-3-electronics/records/2026-10-08-usb-eddy-camera.md) records current replacement Manta, CB1, EBB36 Gen2, Eddy Duo and camera. Earlier faulty Manta was returned. Communication and limited sensor/video results are now recorded, but no blanket full-board PASS, motion/heater commissioning or CAN acceptance is claimed. CEB remains to order.

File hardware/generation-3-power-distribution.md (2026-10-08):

# Generation 3 — PSU enclosure and 24 V power distribution

Status: **agreed topology / engineering specification; not manufactured, purchased or electrically validated**. Updated: 2026-10-08.

This document is the canonical design baseline for the separate Generation 3 power-supply enclosure, panel outlets and CAN power harness. It supplements [final architecture](../docs/final-build-architecture.md), [Bed Node](generation-3-bed-node.md) and [custom CAN node rules](generation-3-custom-can-node-design-rules.md).

## Architecture and enclosure boundaries

- A **separate PSU enclosure** receives 230 V AC through a suitably rated, protective-earth-capable IEC appliance inlet and a **two-pole master switch**; the chosen inlet/switch/fusing topology must be assessed as a complete approved mains assembly.
- Its internal 24 V PSU supplies a covered DC distribution block with **individually protected output branches**. The main control-electronics enclosure is not the source of heater power. No high-current bed supply shall travel through Manta PCB traces, USB wiring, CEB or CAN breakout.
- The preferred final PSU already listed in the repository is **Mean Well LRS-600-24, 24 V / 25 A / 600 W**, **subject to a measured simultaneous-load budget**, derating and thermal validation. Existing prototype PSU use is not final approval. The 150–200 W bed heater target in the frozen final architecture is unchanged; 250/300 W are only design scenarios, not an adopted heater.
- The printed enclosure must be assessed for mains electrical protection, access barriers, strain relief, ventilation, mounting, and a suitably rated flame-retardant material. Ordinary printed ABS/ASA does not automatically qualify as a mains enclosure. Prefer a certified mains compartment/enclosure solution, or a properly qualified insulated/metal sub-enclosure. Protective earth (PE) bonds the PSU chassis and accessible conductive parts as required; it is **not** a substitute for DC return.
- Provide serviceable branch fuses / DC-rated protection, suitably rated terminal blocks, covers, polarity labelling, connector shrouds and an accessible way to isolate all power. Size both positive and return conductors. Never expose live male contacts on the energized PSU panel.
- Any emergency stop / independent heater thermal cutoff remains outside Klipper, Linux and CAN authority. Provide independent bed thermal fuse mounted to the heater assembly and appropriate branch overcurrent protection. Functional heater control remains with a suitably rated **external DC MOSFET stage** under Bed Node control (or Manta control during initial commissioning).

## DC panel connectors and branch allocations

**Connector family selected:** genuine **AMASS XT60E panel-mount XT60-compatible** connectors, mechanically fastened to the PSU enclosure. Exact suffix, gender, orientation, mechanical cutout and mating cable-side item must be chosen from a manufacturer drawing before CAD release. **XT90 is not required in the present baseline**, but may be reconsidered for a future higher-current overall feed.

Select a **recessed/finger-safe female-socket power-supply panel interface** and a compatible male cable plug where appropriate, verified against AMASS drawings and real samples; no accessible energized pins. Each output must be clearly engraved/silkscreen-labelled and keyed/polarised. **Each branch has an independent fuse** and separately routed +24 V and 0 V. Proposed seven-way panel (outlet identities frozen; ratings provisional):

| Port | Destination / purpose | Connector | Design status |
| --- | --- | --- | --- |
| PWR-01 | Manta M8P V2 main logic/controller input / host (VIN or board-designated 24 V input after schematic verification) | XT60E panel | Dedicated protected branch |
| PWR-02 | Manta motor-driver supply domain (VBB/HV selection and board isolation **must be verified**; no assumption of electrically independent rails) | XT60E panel | Dedicated protected branch; actual Manta pins/jumpers TBD |
| PWR-03 | Rear bed-area **heater-power stage**, not CAN/Bed Node logic input | XT60E panel | Dedicated high-current heater branch |
| PWR-04 | Toolhead electronics/heater/extruder supply, delivered to EBB36 via the final **XT30(2+2)** CAN/power harness and an appropriately protected distribution point | XT60E panel | Only **one intentional power feed** to EBB; prohibit accidental parallel feeds |
| PWR-05 | CAN distribution PCB / CEB / low-power Bed Node/RASS logic supply | XT60E panel | Separate logic/CAN supply |
| PWR-06 | Auxiliary 24 V loads such as dedicated USB hub DC/DC, lighting or later spool accessories | XT60E panel | Auxiliary branch; its loads/budget TBD |
| PWR-07 | Labelled capped **SPARE**, normally unpopulated or electrically isolated until commissioned | XT60E panel provision | Reserve, no live exposed contact |

The branch plan must be consolidated during schematic design: a low-current CAN distribution PCB may receive 24 V from PWR-05 while the toolhead's higher-current 24 V originates from PWR-04. **Do not simply join two separately fused 24 V branches on the same unisolated CAN power conductor**. Select one feed per powered segment, or use designed separation of CAN-H/L from the high-current supply path, validated return and fault strategy. Passive CEB ports are **not** independent power outputs or CAN repeaters.

### Wiring topology (functional, not a pin-number drawing)

```text
IEC 230 Vac (L/N/PE) -> rated 2-pole switch + mains protection
                         -> 24 V PSU -> covered +24 V / 0 V DC distributor
                                       |-- F01 -> XT60 PWR-01 -> Manta logic
                                       |-- F02 -> XT60 PWR-02 -> Manta drivers*
                                       |-- F03 -> XT60 PWR-03 -> bed DC heater stage
                                       |-- F04 -> XT60 PWR-04 -> EBB feed design*
                                       |-- F05 -> XT60 PWR-05 -> CAN low-power domain*
                                       |-- F06 -> XT60 PWR-06 -> auxiliary loads
                                       '-- F07 -> XT60 PWR-07 -> isolated spare

Manta CAN -> CEB/passive linear CAN bus -> EBB36 and Bed Node/RASS
Bed Node logic: XT30(2+2) CAN + separately fused low-power 24 V segment*
Bed heater: independent PWR-03 high-current +24 V/0 V -> external
            MOSFET switching stage -> short flexible moving-bed heater cable;
            independent thermal fuse physically on bed
```

*Final separation of motor voltage domains, CAN power branches, physical power injection and grounding is **pending schematic verification**. Do not wire from this functional diagram alone.

## CAN connectors and cable manufacturing

- Connector type: **XT30(2+2), four contacts**: two large contacts for +24 V/0 V and two small contacts for differential CAN-H/CAN-L. **Ordinary 2-pole XT30 is not interchangeable.**
- Candidate **vertical male THT PCB**: **AMASS XT30(2+2)PB-M**, distributor listing **LCSC C19268029**. Candidate mating **female inline cable plug**: **AMASS XT30(2+2)-F**. Catalog designations, physical fit, electrical ratings, actual EBB36/CEB mating gender and precise manufacturer pin numbers are **to be verified from authoritative drawings and samples** before PCB footprint or harness release.
- At the PSU side, use panel XT60E; at CAN breakout / custom node PCB edges, use vertical XT30(2+2) where manufacturer-certified mating pairs fit the geometry.
- Keep **two independent cable assemblies** from main electronics area towards bed rear: (1) **four-core CAN+logic** (+24 V, 0 V, twisted CAN-H/L), with XT30(2+2) mating connectors; (2) **two-core 24 V heater power** from PWR-03 through a current-rated connector to external switching stage. Bed Node is fixed at rear chassis cross-member; only the short cable to the moving Y bed needs continuous-flex rating.
- EBB36 toolhead: four conductor combined CAN/power harness using XT30(2+2), continuously flex-rated in X-chain. The REVO heater, ROTO driver and all attached loads are included in the power budget.
- **Cable candidates only:** LAPP UNITRONIC BUS CAN FD P 2x2x0.5 mm² (manufacturer part 2170279), or chainflex-grade equivalent; 0.5 mm² for low-current Bed Node logic/CAN may be adequate after load/length checks. For moving EBB seek 2x0.75–1.0 mm² power + twisted 2x0.25–0.34 mm² CAN as an alternative if connector terminals and cable dynamic rating permit. Neither is automatically approved.
- Bed heater branch: consider **2x1.5–2.5 mm² flexible wire**, final selection based on actual 150–200 W heater, round-trip length, ambient temperature, routing, voltage drop, motion, fuse trip and connector rating. 0.5/0.75 mm² CAN cable **must not** be used to supply the bed heating element.
- Shielding/drain termination, reference ground strategy, conductor colours, crimp/solder specifications, heatshrink, strain relief, pin-to-pin continuity tests and service loops will be recorded in a separate **versioned harness drawing**. The simplified pairing CAN-H/L + PSU+/- is **not** a verified connector pin assignment.
- The CEB is a passive junction, not an active multiport hub. Maintain a CAN trunk with short stubs and **exactly two 120-ohm terminations at physical endpoints**. Custom Bed Node/RASS each provide two CAN passthrough connectors and switchable 120-ohm termination per [node rules](generation-3-custom-can-node-design-rules.md).

## Release gates / outstanding engineering

1. Confirm PSU nameplate, mechanical fit, fan/derating and complete worst-case load budget including bed, X/Y/Z, EBB, CB2, CAN nodes, fans and peripherals.
2. Confirm Manta V2.0 schematic input names, 24 V VBB/HV relationships, fusing, wiring, jumpers and whether separate PWR-01/PWR-02 circuits truly remain separate.
3. Confirm original AMASS manufacturer drawings, XT60E safe panel gender and XT30(2+2) board/cable mated geometry, pin numbering, thermal/current ratings and panel footprints.
4. Specify DC fuse sizes/type/power breaking ratings according to selected wiring, heater, PSU short circuit capability and connector ratings (no invented amperage).
5. Define documented single-source power injection for EBB, CEB and each custom CAN node; prevent backfeed between PWR-04/PWR-05.
6. Finalize wire gauge/length, harness routing, shield bonds, protective earth, movement, mechanical restraint and bed safety cutoff behavior.
7. Have the mains assembly designed/inspected by a competent person before energization; bench validate each DC branch disconnected from sensitive electronics, then test short circuit/fault protection and heat rise under controlled conditions.

## Procurement status

All XT60E/XT30(2+2) part references and cables above are **selection candidates, not recorded purchases**. The dedicated PSU enclosure, fused panel distributor, custom CAN breakout, Bed Node, heater stage and made-to-measure harnesses are **planned only**.

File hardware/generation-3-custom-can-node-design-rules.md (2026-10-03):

# Generation 3 custom CAN node design rules

This document defines the common electrical, firmware and expansion rules for Revival-designed Klipper CAN boards. It currently applies to the **Revival Bed Node** and the **RASS CAN Node**.

The purpose is to keep both boards maintainable with normal upstream Klipper while deliberately preserving hardware capacity for future sensors and peripherals.

## Frozen firmware policy

Both custom boards shall run **unmodified upstream Klipper MCU firmware**.

This means:

- the MCU firmware must be buildable from the normal upstream Klipper source tree;
- board-specific `make menuconfig` selections, pin maps, Klipper configuration includes and build documentation are expected;
- an upstream-compatible CAN bootloader/update path may be used where appropriate;
- USB boot/recovery support may be provided by the selected MCU and board design;
- Revival-specific behaviour should be implemented in host-side Python modules/services, Klipper configuration/macros, Moonraker integrations or other Linux-host software;
- no production requirement may depend on a private Klipper MCU fork, patched `src/` tree, private MCU protocol command or custom C firmware command.

If a future peripheral cannot be supported without modifying Klipper MCU firmware, the first design responses are to change the peripheral/interface, use an upstream-supported bus primitive, move the logic to the Linux host, or introduce a separate bridge/coprocessor. Accepting a Klipper MCU fork would be an explicit architecture change that must supersede this frozen rule in the Decision Log.

The repository must record the upstream Klipper revision/hash used to validate each released board.

## Host versus MCU responsibility

The custom CAN MCU is responsible for deterministic local I/O that upstream Klipper already supports: pins, timers, ADCs, steppers, heaters/PWM where relevant, and supported bus transactions.

Revival-specific semantics belong on the Linux host whenever practical.

Examples:

- Bed Node: RID interpretation, history and high-level diagnostics are host responsibilities.
- RASS Node: RFID/NFC electrical acquisition may occur on the node, but vendor/tag/material decoding, inventory and profile mapping are host responsibilities.
- CB1 may provide the Linux-host role during bench development; CB2 is the final Generation 3 host.

This boundary deliberately keeps the custom PCBs useful across normal Klipper updates.

## Full unused-pin exposure policy

The Revival does **not** use a minimum-reserve model for its custom CAN boards.

After all frozen production functions are assigned, **every remaining electrically usable MCU pin must be physically exposed for future use** on the Bed Node and RASS CAN Node. The objective is to avoid stranding MCU capability inside the PCB.

This rule applies to all unused MCU pins that can safely be made available, including pins whose alternate functions can provide:

- SPI;
- I2C;
- UART/USART;
- ADC;
- timer/PWM;
- external interrupt/event input;
- ordinary digital GPIO;
- other upstream-Klipper-compatible peripheral functions supported by the selected MCU.

### What counts as exposed

An unused pin is considered exposed only when it is reachable without PCB modification through one of:

- a labelled expansion connector;
- a labelled through-hole header position;
- a deliberately provided, accessible solder pad/test pad intended for expansion.

Merely routing a trace to an inaccessible via does not satisfy this rule.

Where practical, related signals should be grouped into useful expansion headers — for example SPI + CS + IRQ + power, I2C + power, or UART + power — while still exposing any remaining individual pins that do not fit those groups.

### Exceptions

A pin may remain unavailable only when there is a documented hardware reason, for example:

- it is committed to CAN, USB, SWD/debug, BOOT/RESET or the selected bootloader/recovery scheme;
- it is required by the crystal/oscillator or other mandatory clock circuitry;
- it is tied to power, reference, regulator or other non-GPIO MCU functions;
- exposing it would violate MCU boot-strapping requirements or create a credible electrical/safety hazard;
- package-specific restrictions make it unusable in the selected board configuration.

Such pins must still appear in the resource ledger with the reason they are unavailable.

SWD/debug, BOOT and RESET are not treated as lost resources: they must be exposed separately as service/debug access. Where the selected MCU requires manual BOOT/BOOTSEL and RESET intervention for commissioning or recovery, **dedicated tactile pushbuttons shall be fitted on the PCB**, following the serviceability model used by the EBB36.

### Alternate-function documentation

For every exposed unused MCU pin, the released board documentation must record:

- MCU pin name;
- PCB connector/pad and pin number;
- logic voltage;
- ADC capability where applicable;
- timer/PWM capability where applicable;
- SPI/I2C/UART alternate functions that remain usable with the final pin mux;
- boot/debug/electrical caveats;
- any external protection, pull-up/down or filtering already attached to the pin.

This documentation is authoritative for future expansions.

### Bus-oriented expansion

Because future peripherals are likely to use buses, the PCB layout should still group exposed pins into convenient bus-oriented connectors whenever practical.

However, these grouped connectors are **in addition to**, not a substitute for, the full-unused-pin rule. If an MCU has more unused pins than are needed for the grouped SPI/I2C/UART headers, the remaining safe unused pins must still be exposed.

### Power rails

Expansion areas should make nearby access available to:

- GND;
- regulated 3.3 V;
- regulated 5 V where the board power budget supports it.

Available current must be specified in the released board documentation. Expansion connectors must not be treated as an undocumented source of heater, motor or other high-current power.

## Mandatory CAN physical interface

Every Revival-designed CAN node covered by this specification must provide:

- **two equivalent CAN connectors** forming an electrical passthrough of the same bus segment (CAN IN / CAN OUT or equivalent naming);
- CAN-H and CAN-L continued directly between those connectors with the local transceiver attached as a node on that segment;
- the required reference/power conductors for the selected harness architecture, documented per connector;
- a **selectable 120-ohm termination resistor** between CAN-H and CAN-L, enabled only when the board is intentionally used at a physical end of the bus;
- clear silkscreen marking of the termination control and its ON/OFF state;
- CAN-H/CAN-L test points.

The passthrough must remain usable regardless of whether the board's own MCU is powered/operational, except where the final protection scheme makes that physically impossible and the exception is explicitly documented.

A custom node is not design-complete if it has only a single CAN connector. This requirement exists so Bed Node and RASS Node can be placed as intermediate or terminal nodes without redesigning the PCB.

### CEB topology rule

The BIGTREETECH CEB V1.0 is treated as a **passive breakout/junction on one CAN bus**, not as an active switch, repeater or multi-port CAN hub.

Therefore:

- the complete Generation 3 CAN network still uses **exactly two 120-ohm terminations total**, at the two physical ends of the effective bus;
- the CEB termination remains disabled unless the CEB itself is intentionally made a physical endpoint;
- long machine runs should be arranged as an effective linear trunk using node passthrough connectors;
- additional devices connected directly to spare CEB ports should use **short stubs**;
- a multi-arm star with several long CEB-to-node branches is not an acceptable final topology merely because the CEB provides multiple connectors;
- adding extra 120-ohm resistors to individual CEB branches is not a valid fix for a poor star topology.

A preferred Revival physical pattern is to use two long directions from the CEB as the effective trunk and keep the Manta-to-CEB connection very short. For example:

```text
RASS (120R ON) <- Bed Node <- CEB -> EBB36 -> Eddy Duo (120R ON)
                             |
                             +-> Manta M8P V2 (very short stub)
```

Exact node order remains dependent on final physical placement and harness lengths, but the commissioning documentation must identify the two actual bus endpoints and record every 120R jumper state.

## Debug and recovery reserve

Both custom boards must provide practical access to:

- a **dedicated BOOT/BOOTSEL pushbutton** when the selected MCU/boot scheme benefits from or requires manual boot-mode entry;
- a **dedicated RESET pushbutton** when supported/required by the selected MCU;
- the MCU-native debug/programming interface, for example **SWDIO + SWCLK + GND + 3.3 V reference** on a keyed header or clearly labelled service pads for STM32-class designs;
- labelled test points for CAN-H, CAN-L, main logic rails and ground.

SWD is a debug/programming interface, not a pushbutton function; it must remain physically accessible without dismantling or desoldering the board. USB-C service/recovery remains strongly preferred when compatible with the selected MCU and board topology.

## MCU selection rule

The MCU is **not acceptable** merely because it can run Klipper and satisfy the current I/O list.

After allocating all frozen production functions, the selected MCU/package must still permit every remaining electrically usable MCU pin to be exposed in accordance with the full unused-pin policy above.

MCU selection therefore considers:

- upstream Klipper CAN support;
- USB/recovery options;
- timer/stepper resources;
- SPI/I2C/UART peripheral count and pin mapping;
- ADC channel count and quality;
- available GPIO/PWM resources;
- flash/RAM margin;
- package/routing practicality;
- availability and lifecycle;
- ability to expose all remaining electrically usable MCU pins without unsafe pin multiplexing or impractical routing.

A larger MCU/package is preferred over consuming every peripheral at initial release.

## Connector and labelling rules

Exact connector families remain open until PCB layout, enclosure and harness design.

Released boards must nevertheless:

- key external connectors where practical;
- label voltage and signal orientation clearly on silkscreen;
- distinguish 3.3 V logic from any 5 V power rail;
- avoid exposing raw high-current paths on generic expansion headers;
- document connector pinout, logic voltage, maximum current and MCU pin mapping;
- reserve service loops/strain relief where a cable leaves the enclosure.

## Resource ledger

Each released PCB must include a versioned resource ledger in the repository showing:

- MCU part and package;
- each hardware peripheral used by baseline functions;
- each assigned pin;
- each expansion connector;
- every remaining unused MCU pin, its alternate-function capabilities and its physical expansion connector/pad;
- boot/debug pins;
- pins that must never be used because of boot, crystal, USB, CAN or other hardware constraints.

A board is not considered design-complete until this ledger accounts for **every MCU pin** and proves that every electrically usable pin not consumed by the production design is physically exposed, with documented exceptions for pins that cannot safely be made available.

## Safety boundary

Expansion capacity is for diagnostics, sensing and validated auxiliary functions.

No future plug-in expansion may silently become the sole protection for:

- mains isolation;
- protective earth;
- over-current protection;
- heated-bed thermal protection;
- emergency energy removal;
- other safety-critical functions that the Generation 3 architecture requires to remain independent of Linux/Klipper/CAN.

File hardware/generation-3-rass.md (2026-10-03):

# RASS — Revival Active Spool System

This document defines the **RASS (Revival Active Spool System)** architecture for the Generation 3 build.

RASS extends the Generation 3 smart-spool subsystem with **active filament delivery and spool rotation assistance** for a single loaded spool. It deliberately does **not** implement automatic material switching, multi-spool selection or an AMS-style hub.

## Purpose

The target behaviour is:

- identify the loaded spool;
- measure remaining filament mass;
- actively assist spool rotation;
- actively feed filament from close to the spool;
- maintain low, controlled tension in the filament path;
- avoid making the toolhead direct-drive extruder pull against spool inertia;
- detect feed anomalies using multiple independent signals;
- keep the complete system usable with one spool and one filament path.

The toolhead extruder remains the **master extrusion actuator**. RASS only manages upstream supply.

## Functional architecture

```text
                         SPOOL
                           |
                 +---------+---------+
                 |                   |
            RFID/NFC reader       load cell
                 |                   |
          Smart-spool reader / weighing service
                 |
                 +------------ host data / context ------------+
                                                                |
CEB V1.0 CAN -------------------------------------------- RASS CAN Node
                                                                |
                                              +-----------------+----------------+
                                              |                 |                |
                                       spool-drive motor    feeder motor    buffer/encoders
                                    |
                               PTFE path
                                    |
                             toolhead extruder
                                    |
                                  nozzle
```

## Single-spool rule

RASS is intentionally a **single-spool active feeder**.

It does not require:

- filament selector;
- cutter for material change;
- multi-spool hub;
- automatic spool switching;
- purge tower logic for colour changes.

This keeps the mechanism mechanically simpler and allows the design effort to focus on smooth, measurable and reliable filament delivery.

## Spool drive

The spool holder uses an assisted-drive mechanism so that the toolhead extruder does not need to accelerate the full spool mass through filament tension.

Preferred concept:

```text
          SPOOL
       +---------+
       |         |
       +---------+
        O       O
        |       |
        |       +-- passive support roller
        |
        +---------- driven roller
```

The exact implementation remains open and may use:

- geared DC motor;
- compact stepper;
- compliant friction roller;
- driven axle/adapter if later testing shows it is more universal.

The spool drive must provide **assistance**, not rigid speed enforcement.

Its control objective is to keep the spool rotating freely with slight positive control while avoiding overfeeding or pulling filament backwards unexpectedly.

## Active feeder near the spool

A compact dual-drive feeder is mounted close to the spool.

Its role is to push filament into the downstream PTFE path so the toolhead direct-drive extruder does not have to overcome:

- spool inertia;
- spool bearing/roller friction;
- heavy full-spool acceleration;
- poor cardboard-spool rolling;
- long-path drag.

The upstream feeder must never replace the toolhead extruder as the source of extrusion precision.

The toolhead extruder still owns:

- commanded extrusion distance;
- pressure advance;
- retraction;
- flow calibration;
- volumetric-flow control.

## Buffer / dancer mechanism

A mechanical or sensorised buffer is required between the active feeder and the toolhead extruder.

Purpose:

- decouple the upstream feeder from instantaneous extrusion motion;
- prevent two motors from fighting each other;
- absorb short acceleration/retraction differences;
- provide an independent tension/position signal.

Conceptual state logic:

```text
buffer pulled/tensioned
        -> feeder speeds up

buffer centred
        -> feeder tracks nominal supply

buffer relaxed/overfilled
        -> feeder slows or stops

reverse/retract condition
        -> feeder may reverse gently if required
```

The exact buffer implementation is intentionally open. Candidate mechanisms include:

- spring-loaded dancer arm;
- linear floating guide;
- short compliant filament loop with optical/Hall sensing;
- multi-position sensor rather than simple binary detection.

## Toolhead relationship

The toolhead direct-drive extruder remains the master.

RASS must therefore operate as a **follower supply system** rather than as a second synchronous extruder.

Preferred control hierarchy:

```text
Klipper extrusion command
        |
        v
toolhead direct drive
        |
        v
buffer position/tension changes
        |
        v
RASS feeder adjusts upstream delivery
        |
        v
spool-drive motor assists rotation
```

Nozzle-side extrusion calibration must remain independent of small RASS control errors.

## Integration with Smart Spool System

RASS reuses the Generation 3 smart-spool hardware and data model.

Shared functions include:

- RFID/NFC identification;
- vendor decoder registry;
- adaptive unknown-tag learning;
- brand/material database;
- spool tare data;
- load-cell weighing;
- remaining filament calculation;
- local spool inventory;
- UI integration.

RASS adds:

- driven spool support;
- feeder motor;
- feeder motion sensing;
- buffer/dancer sensing;
- active tension management;
- additional feed-fault diagnostics.

## Weighing architecture

The weighing system remains authoritative for stable remaining-filament measurements.

All parts that mechanically carry the spool must be included in the calibrated load path.

Preferred arrangement:

```text
       spool
         |
  driven/passive rollers
         |
  RASS spool platform
  - motor
  - reader
  - rollers
         |
      load cell
         |
       frame
```

The tare model therefore includes the RASS holder assembly separately from the empty-spool tare.

The design must avoid mechanical bypasses that transfer spool weight directly to the frame.

## Sensors and diagnostics

RASS should expose enough independent signals to distinguish different failure modes.

Target signals:

- RFID/NFC spool identity;
- stable spool mass;
- feeder motor command;
- feeder motion/encoder feedback;
- buffer/dancer position;
- spool-drive command;
- optional spool rotation feedback;
- filament-present sensor;
- toolhead filament-motion sensor if that Generation 3 candidate is adopted;
- commanded toolhead extrusion.

Example diagnostic cases:

```text
toolhead commands extrusion
+ buffer becomes increasingly tensioned
+ feeder does not advance
=> probable feeder fault or upstream jam

feeder motor turns
+ feeder encoder reports no filament motion
=> feeder slip / filament grinding

feeder advances
+ buffer remains tensioned
=> spool blocked or spool-drive assistance insufficient

spool-drive turns
+ expected rotation feedback absent
=> spool/roller slip

calculated consumption changes
+ stable scale mass does not reconcile later
=> weighing/tare/inventory anomaly
```

These diagnoses are advisory until validated experimentally.

## Controller and host link

The **production RASS motion/sensing controller is a custom Klipper-compatible CAN node** designed specifically for the Revival and connected to the Generation 3 CAN backbone through the BIGTREETECH CEB V1.0. It follows the common [custom CAN-node design rules](generation-3-custom-can-node-design-rules.md).

Production-controller requirements:

- MCU supported by upstream Klipper with a validated CAN transport;
- dedicated CAN transceiver and suitable bus protection;
- **two equivalent CAN connectors providing electrical passthrough (CAN IN / CAN OUT)** so the RASS Node may be inserted inline;
- selectable 120-ohm termination so the board can be correctly placed at a physical bus end if required;
- motor-driver interfaces sized for the spool-drive and feeder motors;
- buffer/dancer sensor inputs;
- feeder encoder/motion inputs;
- filament-presence and optional spool-rotation feedback inputs;
- physical exposure of **every remaining electrically usable MCU pin** under the common custom-node rules after the feeder, spool-drive, RFID reader, buffer, encoder and production sensors are allocated;
- service/status LEDs;
- dedicated **BOOT/BOOTSEL and RESET tactile pushbuttons** where applicable to the selected MCU, following the EBB36-style service model;
- dedicated native debug/programming access (for example SWD header/pads on STM32);
- USB-C service/recovery preferred where the selected MCU supports it cleanly.

Normal production communication is **CAN through the CEB V1.0**. Wi-Fi is not part of the production RASS control path.

The RASS CAN Node may host the **physical RFID/NFC reader interface** and acquire the tag traffic needed by the Smart Spool subsystem, but it must remain **interpretation-free**. Its responsibility is to read and forward low-level tag data/events to the Linux host over the machine data path. It must not decide manufacturer, material, colour, profile, spool identity semantics or vendor format.

All RFID/NFC interpretation belongs to the host service: **CB1 during bench/prototype work and CB2 in the final Generation 3 machine**. The host owns decoder plugins, vendor-format interpretation, Revival Spool Tag parsing, database/inventory logic and profile mapping.

The exact upstream-compatible transport for variable RFID/NFC payloads over the RASS CAN/Klipper link remains an implementation item. Prefer a host-side service/extension and standard upstream Klipper bus/MCU mechanisms. **The production RASS MCU shall run unmodified upstream Klipper firmware.** If a proposed RFID reader or transport would require patched Klipper MCU C code or a private MCU protocol command, change the reader/interface/host architecture instead of embedding that requirement in the production firmware.

## Motor selection philosophy

Exact motors are not frozen.

### Feeder motor

Requirements:

- controllable low-speed torque;
- smooth reversal;
- compact size;
- low heat;
- sufficient force for PTFE-path assistance without crushing filament.

A compact stepper is currently the most likely direction because it gives measurable feed motion and deterministic low-speed control.

### Spool-drive motor

Requirements:

- low speed;
- compliant/forgiving torque delivery;
- low noise;
- safe stall behaviour;
- minimal disturbance to load-cell readings.

A geared DC motor or compact stepper are both candidates.

#### Prototype candidate already on hand — 28BYJ-48 5 V + ULN2003

A **28BYJ-48 5 V geared stepper** with its common **ULN2003 driver board** is available from existing parts and is now the preferred **prototype candidate for spool-rotation assistance**.

Why it is worth testing:

- integrated reduction gives useful low-speed torque;
- naturally suited to slow spool rotation;
- direction can be reversed under MCU control;
- the ULN2003 board is already available for early bench tests;
- its cost to prototype is effectively zero because the parts are already on hand.

Intended use:

```text
temporary bench MCU
   |
IN1..IN4
   |
ULN2003
   |
28BYJ-48 5 V
   |
driven spool roller / spool assist
```

This motor is **not a feeder candidate**. The gearbox backlash and modest dynamics make it unsuitable for the filament-feeder function that must respond accurately to buffer demand. The upstream filament feeder still targets a compact stepper, likely NEMA14-class or equivalent, with a dual-drive filament mechanism.

The 28BYJ-48 remains a **prototype candidate**, not frozen production hardware. It must be validated with a full 1 kg spool, the real roller geometry and the final load-cell arrangement. Acceptance criteria include sufficient torque, acceptable noise, controlled reversing, no harmful vibration into the weighing system and graceful freewheel/disengagement behaviour if RASS is disabled.

## Filament compatibility

RASS must be designed to work with:

- PLA;
- PETG;
- ASA;
- ABS where used;
- TPU/flexible materials.

The feeder path must minimise drag and avoid excessive pinch force.

TPU compatibility is a design constraint, not an optional afterthought.

## Failure and fallback behaviour

RASS must fail gracefully.

If RASS is unavailable, the printer should still be capable of manual/passive spool operation where mechanically possible.

Examples:

- RFID failure -> allow manual spool/profile selection;
- scale failure -> use software consumption estimate and manual inventory;
- spool-drive failure -> disengage or freewheel;
- feeder failure -> disable active feed and allow passive/manual path if safe;
- buffer sensor failure -> disable active-follow mode rather than guessing.

RASS failure must not force unsafe extrusion behaviour.

## User experience

Target normal workflow:

```text
install spool
   |
tag identified
   |
stable mass measured
   |
remaining filament shown
   |
RASS feeder/path self-check
   |
load filament
   |
active tension control enabled
   |
print
```

During printing, the HDMI5/Mainsail interface may expose:

- spool identity;
- remaining mass;
- RASS state;
- buffer position;
- feeder status;
- spool-drive status;
- warnings/faults.

### Local RASS Spool Panel

Generation 3 also includes a **second small touchscreen mounted locally next to the RASS/spool assembly**. This is a dedicated spool-status/control HMI, not a second copy of the full KlipperScreen interface.

The preferred architecture is a **small self-rendering serial HMI** connected by a wired host link (normally USB-to-serial or equivalent) to the Linux host. It does **not** consume the CB2's primary HDMI display path and is not driven by the RASS MCU.

Target information shown locally:

- spool manufacturer/product where known;
- material and colour;
- tag/identification state;
- remaining mass and percentage, plus estimated length where available;
- RASS state;
- filament-present state;
- buffer/dancer state;
- feeder/spool-drive warnings;
- current nozzle temperature and whether filament handling is permitted.

The panel provides touch controls for at least:

- **LOAD / CARGAR FILAMENTO**;
- **UNLOAD / DESCARGAR FILAMENTO**.

These controls are **requests to the Linux host**, never direct motor commands. The display may show a button as enabled only when the host says the action is currently allowed, but the host must independently re-check all interlocks when the touch event arrives.

The load/unload action is permitted only when all applicable conditions are true:

- Klipper is connected and in a normal ready state;
- there is **no active print**, including no paused print that could later resume;
- no homing, probing, calibration or other incompatible motion/action is active;
- required extrusion/RASS MCUs and sensors are online and not reporting a fault;
- the toolhead/extrusion path is stationary and in a known-safe state;
- the hotend is at or above the configured safe extrusion/minimum-extrude temperature and within valid temperature limits;
- RASS buffer/filament state is compatible with the requested direction;
- any additional interlock introduced later by validated RASS hardware also passes.

When a condition is not met, the corresponding button remains disabled and the panel should show a short reason such as **PRINT ACTIVE**, **HOTEND COLD**, **RASS FAULT**, **FILAMENT ALREADY LOADED** or **NO FILAMENT TO UNLOAD**.

The host-side RASS/Spool service owns this gating policy. The HMI firmware/layout is presentation only and must not be treated as a safety boundary.

Normal printing should not require the user to manually tune feeder speed.

## Frozen architectural decisions

- the name is **RASS — Revival Active Spool System**;
- RASS is a single-spool system;
- RASS extends the Generation 3 Smart Spool System;
- spool identification and automatic weighing remain integrated;
- the spool receives active rotation assistance;
- a dedicated feeder near the spool actively supplies filament into the PTFE path;
- the toolhead direct-drive extruder remains the master extrusion actuator;
- an intermediate buffer/dancer decouples the upstream feeder from toolhead extrusion;
- RASS uses sensor feedback rather than fixed feeder/spool speeds;
- the complete spool-support mechanism remains inside the calibrated load-cell path;
- RASS diagnostics compare multiple signals to detect feed anomalies;
- RASS is controlled by a **custom Klipper-compatible CAN MCU** connected through the CEB V1.0;
- the RASS MCU runs **unmodified upstream Klipper firmware**; Revival-specific semantics and decoding remain on the Linux host;
- CAN is the normal production RASS host link;
- the RASS node acquires RFID/NFC reader data but performs **no tag/vendor/material interpretation**;
- raw/low-level RFID/NFC observations are forwarded to the Linux host for decoding and inventory/profile logic;
- a dedicated **local RASS Spool Panel** touchscreen is mounted beside the spool/RASS assembly for spool information and guarded LOAD/UNLOAD requests;
- the local panel never directly actuates motors; the Linux host owns action gating and re-validates interlocks at execution time;
- passive/manual fallback remains a design requirement;
- after all production functions are allocated, the RASS PCB exposes **every remaining electrically usable MCU pin**, with SPI/I2C/UART/ADC/GPIO/PWM alternate functions documented and any unavailable pins justified;
- exact MCU, CAN transceiver, motors, motor drivers, buffer geometry and spool-drive mechanism remain open until electrical/mechanical prototyping.

## Open component-level decisions

- production RASS MCU/package selection that satisfies the frozen RASS functions while allowing all remaining electrically usable MCU pins to be physically exposed;
- CAN transceiver/protection implementation;
- exact RFID/NFC reader electrical interface on the RASS PCB;
- exact host transport/API for forwarding raw RFID/NFC observations over the CAN/Klipper path without embedding decoder logic in the MCU;
- CAN connector family and final physical bus position/stub length; CAN IN/OUT passthrough and termination jumper are mandatory;
- feeder motor type/model;
- spool-drive production motor type/model; **28BYJ-48 5 V + ULN2003 is the preferred prototype candidate**;
- motor-driver topology;
- dual-drive feeder geometry;
- feeder encoder/motion sensor;
- buffer/dancer mechanical design;
- buffer position sensor technology;
- spool-rotation sensor/encoder if required;
- PTFE path length and routing;
- drive-roller material and diameter;
- freewheel/disengagement mechanism;
- smart-spool reader/controller board remains a separate decision in the Smart Spool subsystem;
- final interaction with the future toolhead filament-motion sensor;
- calibration procedure for active tension control;
- mechanical filtering required to keep motor activity from corrupting load-cell readings;
- exact RASS Spool Panel model, size, enclosure and wired host interface; a compact serial HMI is the preferred direction.

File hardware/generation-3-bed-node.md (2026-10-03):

# Generation 3 Revival Bed Node

This document defines the planned **Revival Bed Node**, a custom dual-interface **CAN + USB Klipper MCU** mounted in a printed enclosure on the **fixed rear cross-member of the historical lower frame**, close to the moving Y/bed assembly. Normal production communication is over the Generation 3 CAN network through the BIGTREETECH CEB V1.0; USB-C remains available for first flash, recovery, bench diagnostics and an optional alternate Klipper transport.

The design follows the same distributed-control philosophy used by the EBB36 Gen2 on the toolhead, but it is intentionally optimized for the heated bed rather than reusing a toolhead board with unused functions.

## Architectural decision

The final Generation 3 bed architecture is split into two implementation stages.

### Stage A — conventional wiring first

The printer may be commissioned before the custom Bed Node PCB exists.

Initial bed wiring remains conventional:

- bed heater power switched by an external MOSFET controlled from the main electronics;
- bed thermistor wired back to the Manta;
- permanent bed accelerometer provided by the existing/selected USB S2DW-class solution;
- dedicated bed branch fuse;
- independent thermal fuse physically attached to the bed/heater assembly.

This stage is deliberately valid and supported. The Bed Node must **not** block Generation 3 commissioning.

### Stage B — custom Revival Bed Node

After the custom PCB is designed, assembled and validated, bed-local functions migrate to a dedicated MCU connected normally to the Generation 3 CAN network through the **BIGTREETECH CEB V1.0**. A USB-C port remains on the board for first flash, recovery, bench diagnostics and optional alternate USB runtime operation. The Bed Node itself remains **fixed to the chassis**; only the short output harness from the rear cross-member to the moving bed must be highly flexible.

Target topology:

```text
Manta M8P V2 CAN
       |
       v
BIGTREETECH CEB V1.0
       |
       +-- CAN-H / CAN-L --------------------------+
                                                     |
24 V logic / auxiliary feed ------------------------+----> Revival Bed Node
                                                     |      fixed rear cross-member
USB-C service / recovery / alternate runtime -------+             |
                                                                   |
24 V PSU -> dedicated bed fuse -> heater power stage --------------+
                                                                   |
                                                     short flexible bed harness
                                                     +---------+---------+---------+
                                                     |         |         |
                                                  heater   thermistor  remote IMU
                                                     |
                                              independent thermal fuse path
                                                     |
                                                  moving bed
```

The normal Bed Node data path is **CAN through the CEB**. The CAN/logic feed and optional USB-C service cable do not need to be highly flexible because the board is fixed to the rear cross-member. Only the short Bed Node-to-bed harness sees continuous Y-axis motion.

CAN and USB carry **control/data only**. Heater energy remains on the dedicated fused 24 V high-current path and must never be routed through the CEB or USB connector.

## Why a custom board

A dedicated bed board avoids carrying several separate moving signal cables and lets the bed assembly become a single Klipper-controlled subsystem.

Target local functions:

- bed temperature sensing;
- permanent Y-axis accelerometer through a **small remote IMU PCB mounted rigidly on the moving bed/carriage**;
- **local chassis accelerometer on the Bed Node PCB** to measure vibration at the rear lower structure;
- **second remote frame accelerometer** mounted near the top of the flat steel frame;
- local bed-heater MOSFET gate control;
- secondary temperature sensing for thermal-gradient/diagnostic use;
- 24 V voltage/current monitoring;
- local PCB/power-stage temperature monitoring;
- RGB under-bed / under-frame status and decorative lighting;
- future RID diagnostics;
- service/status indication and auxiliary expansion I/O.

The board must not include unnecessary toolhead-specific functions such as an extruder driver.

## MCU direction

A **Klipper-supported MCU with a robust CAN implementation and native/accessible USB recovery path** is required. The Bed Node follows the common [custom CAN-node design rules](generation-3-custom-can-node-design-rules.md). The production design must support:

- normal Klipper communication over CAN;
- USB-C first-flash and recovery access;
- optional alternate Klipper communication over USB for bench/service use;
- SPI for LIS2DW-class accelerometers;
- ADC inputs for thermistors and diagnostics;
- sufficient GPIO;
- low-cost, serviceable components with good upstream support;
- a package/pinout that allows every remaining electrically usable MCU pin to be exposed after all frozen Bed Node functions are assigned.

The CAN physical layer requires a dedicated transceiver, ESD/transient protection appropriate to the final harness, **two equivalent CAN connectors implementing electrical passthrough (CAN IN / CAN OUT)**, and a selectable **120-ohm termination** so the Bed Node can operate either as an intermediate node or at a physical end of the bus. RP2040 remains a candidate only with a validated Klipper/Katapult CAN implementation; STM32 parts with well-supported CAN peripherals are also candidates. The exact MCU, transceiver and connector family are not yet frozen at component level.

## Klipper integration model

The Bed Node is a normal secondary Klipper MCU.

Production CAN configuration:

```ini
[mcu bed]
canbus_uuid: <REVIVAL_BED_NODE_CAN_UUID>
```

Alternate USB bench/service configuration:

```ini
[mcu bed]
serial: /dev/serial/by-id/<REVIVAL_BED_NODE_ID>
```

The hardware exposes both transports, but the production configuration uses **CAN as the normal runtime link**. USB is retained as a recovery/diagnostic path and may be used as an alternate runtime transport with the matching Klipper firmware build; the same physical MCU must not be configured twice as if CAN and USB were two independent MCUs.

Klipper then references pins on that MCU by prefix:

```ini
[heater_bed]
heater_pin: bed:<HEATER_GATE_PIN>
sensor_type: <FINAL_SENSOR_TYPE>
sensor_pin: bed:<BED_THERMISTOR_PIN>
control: pid
min_temp: <SAFE_MIN>
max_temp: <SAFE_MAX>
```

The exact pins, thermistor type and temperature limits remain placeholders until the PCB, heater and sensor are released.

### Bed accelerometer

Because the Bed Node PCB is fixed to the rear frame cross-member, the accelerometer must **not** be mounted on the main Bed Node PCB. A small remote IMU daughterboard is mounted rigidly on the moving bed/Y-carriage and connected to the Bed Node by a short flexible cable.

Preferred topology:

```text
Revival Bed Node (fixed)
        |
      SPI
        |
short flexible cable
        |
Revival Bed IMU (moving)
        |
      LIS2DW
```

The remote IMU PCB should contain as little as practical beyond the accelerometer, decoupling and connector so moving mass remains negligible.

Conceptual Klipper structure:

```ini
[lis2dw bed_accel]
cs_pin: bed:<CS_PIN>
spi_bus: <BED_NODE_SPI_BUS>
axes_map: <MEASURED_ORIENTATION>
```

and:

```ini
[resonance_tester]
accel_chip_x: <toolhead accelerometer>
accel_chip_y: lis2dw bed_accel
probe_points:
    <safe test point>
```

The final syntax must be validated against the Klipper version in use when the board is commissioned.

## Structural vibration sensing

The Bed Node is also the Generation 3 **structural vibration acquisition hub**.

The target sensor set is:

1. **Toolhead accelerometer** on the EBB36 Gen2 — moving X/toolhead response.
2. **Remote bed IMU** connected to the Bed Node — moving Y/bed response.
3. **Local chassis IMU** mounted directly on the fixed Bed Node PCB — rear/lower-structure response.
4. **Remote frame-top IMU** connected to the Bed Node — response of the upper region of the original flat steel frame.

Conceptual topology:

```text
                    FRAME-TOP IMU
                         |
                         | dedicated robust link
                         |
EBB36 IMU ----> Klipper/RID <---- Bed Node local IMU
   |                                      |
 toolhead                           lower/rear chassis
                                          |
                                          +---- remote BED IMU
                                                moving Y bed
```

The purpose is not to replace normal Klipper Input Shaper tuning. The **bed IMU** remains the Y-axis tuning sensor, while the chassis and frame-top IMUs provide structural reference channels for RID and engineering analysis.

### Multi-sensor comparison goals

RID may compare simultaneous or repeatable captures to distinguish:

- motion dominated by the bed;
- motion dominated by the toolhead;
- structural amplification in the flat steel frame;
- energy transmitted into the lower threaded-rod structure;
- new resonances caused by loose fasteners, rail alignment changes, belt tension changes or component ageing;
- changes between an empty bed and a heavy printed part.

The project should preserve baseline spectra so later captures can be compared over time.

### Electrical interface

The bed IMU is close enough for a short flexible SPI connection.

The frame-top IMU is much farther away. The board should therefore reserve a **separate interface** for it instead of assuming that a long unbuffered high-speed SPI cable will always be reliable.

Design provisions should include:

- independent chip select / bus assignment;
- configurable lower SPI speed where supported;
- series damping resistors;
- ground-referenced twisted conductors;
- robust keyed connector;
- PCB footprints or an adapter option for buffered/differential signalling if real-machine tests show it is necessary.

The exact physical signalling method for the frame-top IMU remains open until cable-length/EMI testing is performed.

## RGB status / decorative lighting

The Bed Node will provide a dedicated output for **under-bed / under-structure RGB lighting**.

The preferred implementation is a 24 V common-anode/common-supply analogue RGB strip driven by three local MOSFET PWM channels:

```text
24 V RGB strip
   |
   +-- R --> MOSFET --> Bed Node PWM
   +-- G --> MOSFET --> Bed Node PWM
   +-- B --> MOSFET --> Bed Node PWM
```

This keeps the lighting compatible with the printer's 24 V distribution and avoids requiring addressable LED electronics for the basic status function.

The RGB lighting has two roles:

- decorative ambient lighting beneath the bed / historical lower structure;
- machine-status indication.

Initial status language:

- green — print completed;
- red — error / fault;
- amber/yellow — paused / operator attention;
- blue — heating / preparation;
- white or subdued neutral — normal/ready state;
- other colours — maintenance, diagnostics or future RID states.

The exact colours and transitions remain a UI decision and may be refined later.

Klipper should expose the output through a normal RGB LED abstraction where practical, allowing macros to change the state without custom MCU firmware.

## Sensor and telemetry capacity

The Bed Node should collect as much **useful, actionable** information as practical without compromising heater safety or adding fragile complexity.

High-priority measurements:

- primary bed NTC for Klipper control;
- secondary bed temperature channel for thermal-gradient/diagnostic comparison;
- local PCB/power-stage temperature;
- heater current;
- local 24 V rail voltage;
- heater command/PWM state;
- local chassis acceleration;
- moving-bed acceleration;
- frame-top acceleration.

This enables derived values such as:

- heater electrical power;
- apparent heater resistance trend;
- warm-up/cooldown rate;
- voltage sag under heater load;
- commanded-heater versus measured-current mismatch;
- long-term thermal and vibration signatures.

Example derived calculations:

```text
R_heater = V / I
P_heater = V * I
```

These values are diagnostic only and do not replace electrical protection.

The PCB follows the [full unused-pin exposure policy](generation-3-custom-can-node-design-rules.md). **After** the bed heater, thermistors, current/voltage telemetry, RGB outputs and all production accelerometers are allocated, every remaining electrically usable MCU pin must be brought out to a labelled expansion connector, header position or accessible expansion pad.

Where the final pin mux permits it, exposed pins should be grouped into useful SPI, I2C, UART, ADC and GPIO/PWM expansion areas, but no otherwise-usable unused pin may be hidden merely because the minimum grouped connectors already exist.

BOOT/RESET and the native debug interface remain separately exposed as service resources. When applicable to the selected MCU, the Bed Node shall include **dedicated BOOT/BOOTSEL and RESET tactile pushbuttons**, comparable to the service controls on the EBB36. The native debug interface (for example SWDIO/SWCLK/GND/3V3 on STM32) shall be available on a dedicated header or clearly labelled service pads. Any MCU pin that cannot be exposed must be listed in the Bed Node resource ledger with the specific hardware reason.

## Building and flashing Klipper firmware

The Bed Node shall use **unmodified upstream Klipper MCU firmware**. A private Revival Klipper MCU fork, patched Klipper `src/` tree or custom MCU command is outside the frozen architecture. Revival-specific behaviour must remain in normal Klipper configuration/macros or Linux-host software wherever practical.

For an RP2040-class design, the normal process is:

1. Install/maintain the Klipper source tree on the CB2 or temporary Linux host.
2. Run `make menuconfig`.
3. Select the MCU family matching the Bed Node hardware, for example RP2040.
4. Select **CAN bus** as the normal production communication interface. Build a USB-runtime image only when intentionally using the alternate service mode.
5. Build with `make`.
6. Flash the resulting firmware using the MCU's supported USB bootloader/recovery method for first commissioning, or the validated CAN bootloader/update path once established.
7. For CAN operation, identify the Bed Node `canbus_uuid`; for alternate USB operation, identify its stable `/dev/serial/by-id/` path.
8. Add the selected transport to the printer configuration as `[mcu bed]`.
9. Restart Klipper and verify MCU communication before enabling any heater output.

For an RP2040 reference implementation, initial flashing is expected to use the ROM USB mass-storage boot mode (BOOTSEL) or a documented equivalent. Where applicable, **BOOTSEL and RESET will be real PCB pushbuttons rather than recovery-only test pads**, so normal commissioning/recovery does not require jump wires or desoldering.

Conceptually:

```text
Klipper source
   |
make menuconfig
   |
select MCU + CAN
   |         \
   |          \-> optional USB runtime/service build
   |
make
   |
klipper firmware image
   |
BOOT/DFU/UF2 method
   |
Revival Bed Node
   |
CAN UUID discovery
   |
   +-- optional USB enumeration
   |
canbus_uuid
   |
   +-- optional /dev/serial/by-id/...
   |
[mcu bed]
```

### Firmware-update strategy

The PCB should support **two levels of recovery**:

- normal in-system firmware update over a validated CAN/Katapult path where supported;
- USB-C first-flash/service update and hardware recovery using accessible BOOT/RESET controls or test pads.

The design must never require heater power to be connected merely to flash or recover the MCU.

The repository should eventually contain:

- the exact `make menuconfig` selections;
- generated/validated firmware-build instructions;
- the Bed Node pin map;
- the Klipper include file;
- first-flash and recovery procedures;
- firmware revision/hash used during validation.

## CAN / USB behavior and failure handling

The Bed Node is a Klipper MCU, not an autonomous heater controller.

If the Bed Node disconnects from its selected runtime transport (normally CAN) or stops communicating, Klipper must treat this as an MCU failure and stop the print/heating process.

The design must never depend on USB/Klipper alone for thermal safety.

Independent safety remains mandatory:

```text
24 V PSU
   |
bed branch fuse
   |
local heater power path
   |
MOSFET
   |
independent thermal fuse
   |
heater
```

The thermal fuse must interrupt heater energy even if:

- Klipper crashes;
- CB2 crashes;
- CAN communication is lost or the alternate USB link disconnects;
- Bed Node firmware locks;
- MOSFET fails short.

## Heater power stage

The final Bed Node may place the bed MOSFET physically near the bed to shorten the switched high-current path.

Design rules:

- do not route heater current through small MCU-board traces/connectors;
- use a power stage explicitly sized for the final 24 V bed current with thermal margin;
- use suitable copper area / bus structure / connector rating;
- keep logic and thermistor routing away from the high-current switching loop;
- provide strain relief for the moving 24 V pair;
- retain a dedicated branch fuse upstream;
- retain the independent thermal fuse at the heater/plate.

The exact MOSFET, gate driver, connector and PCB copper geometry remain open.

## Mechanical placement

The Bed Node is mounted in a **printed fixed enclosure on the rear transverse member of the original threaded-rod structure**.

This location is preferred because:

- the incoming CAN, logic-power and optional USB-C service harness can be fixed or only gently flexed;
- the power stage and MCU do not add moving Y mass;
- the board can be larger and better cooled than a bed-mounted PCB;
- service access is easier;
- only a short harness must flex with the bed;
- the local MOSFET remains close to the heater while still being chassis-mounted.

The moving harness from Bed Node to bed carries only the functions that physically terminate on the moving assembly:

- heater power pair;
- thermistor pair;
- remote-IMU cable;
- thermal-fuse/heater series path as required by final wiring.

The printed enclosure must provide protected connectors, strain relief, ventilation appropriate to the MOSFET losses and finger-safe separation from any exposed power terminals.
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

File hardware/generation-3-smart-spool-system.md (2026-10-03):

# Generation 3 smart spool system

This document defines the target **Revival Smart Spool System** for the Generation 3 build.

The objective is to reproduce the useful part of the automatic-spool experience of modern systems while keeping the Revival independent, open, vendor-neutral and extensible:
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

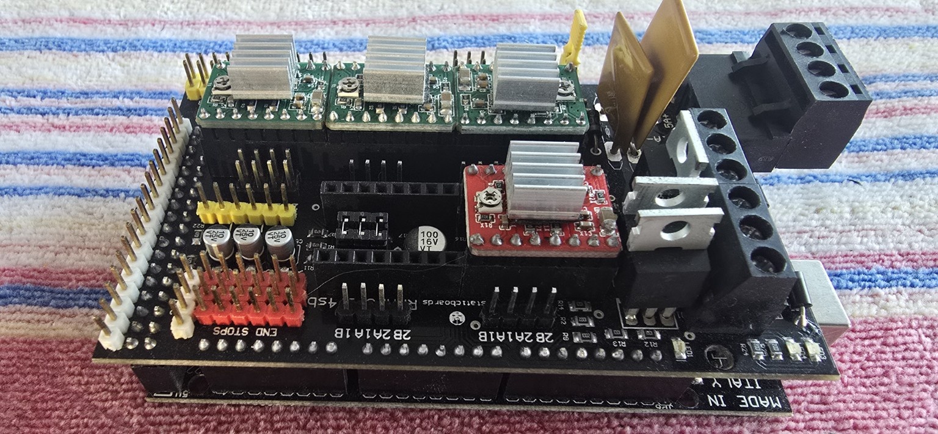
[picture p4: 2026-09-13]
photos/02-teardown/derived/component-inventory/TD-20260913-194-ramps-stack-with-stepper-drivers-overview.jpg

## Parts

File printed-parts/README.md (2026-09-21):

# Printed parts

The [original design archive](original-designs/README.md) contains historical Prusa i3 single-frame and Greg/Wade STL/SCAD files with pinned provenance. Use the [original printed-parts catalogue](original-designs/Original-Printed-Parts.md) to find a model by assembly role, or the [small extruder gear](original-designs/Small-Extruder-Gear.md) page for the Stage H candidate.

The published sets are preserved locally, but exact compatibility with every recovered component remains under verification. Original downloads stay unchanged; project adaptations, print settings and fit results must be recorded separately.

New parts will be published, whenever possible, as editable CAD source files together with STEP, STL and reference 3MF projects.

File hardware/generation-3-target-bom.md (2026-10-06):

# Generation 3 target hardware BOM

This is the target hardware set for the **Revival 2026 final build**. It records architectural selections early so later purchases and CAD decisions remain consistent. It is **not** an instruction to skip the original Arduino/RAMPS or Re-ARM generations.

See [`../docs/final-build-architecture.md`](../docs/final-build-architecture.md) for the full architecture and safety boundaries.

See [`generation-3-linear-motion.md`](generation-3-linear-motion.md) for the frozen Generation 3 linear-motion and alignment architecture.

See [`generation-3-smart-spool-system.md`](generation-3-smart-spool-system.md) for the Generation 3 spool-identification, vendor compatibility, adaptive tag learning and automatic-weighing architecture.

See [`generation-3-rass.md`](generation-3-rass.md) for the RASS active single-spool feeding, driven-spool assistance and buffer/dancer architecture.

See [`generation-3-extrusion-toolhead.md`](generation-3-extrusion-toolhead.md) for the preferred Roto + Revo Generation 3 extrusion/toolhead direction and material-use priorities.

See [`generation-3-main-camera.md`](generation-3-main-camera.md) for the frozen Innomaker U30CAM-4K-S1 USB/UVC main frame-camera selection and bench-validation plan.

See [`generation-3-enhancement-candidates.md`](generation-3-enhancement-candidates.md) for remaining fault-detection, cleaning, safety-control, maintenance and electrical-monitoring candidates, plus the recorded promotion of Eddy Duo probing into the frozen architecture.

See [`generation-3-procurement-status.md`](generation-3-procurement-status.md) for actual purchases, pending acquisitions and bench-test status.

See [`generation-3-bed-node.md`](generation-3-bed-node.md) for the staged heated-bed control architecture and custom CAN-primary / USB-service Klipper MCU.

See [`generation-3-custom-can-node-design-rules.md`](generation-3-custom-can-node-design-rules.md) for the frozen upstream-Klipper firmware policy and the requirement to expose every remaining electrically usable MCU pin on the Revival Bed Node and RASS CAN Node.

## Frozen selections

| Subsystem | Target component / architecture | Status |
|---|---|---|
| Main controller | BIGTREETECH Manta M8P V2.0 | Frozen; purchased |
| Linux host | BIGTREETECH CB2 | Frozen; not yet purchased |
| Main stepper drivers | TMC2209 plug-in modules for Manta; base allocation X/Y/Z0/Z1 | Frozen architecture; 6× BTT TMC2209 V1.3 purchased (4 base + 2 spare) |
| Local display | BIGTREETECH HDMI5, 5-inch capacitive touchscreen | Frozen |
| Display integration | Custom retro/industrial ASA enclosure + KlipperScreen theme | Frozen concept |
| RASS local display | Small dedicated touchscreen beside spool/RASS assembly; spool status plus guarded LOAD/UNLOAD controls | Frozen architecture; serial HMI / wired host link preferred, exact model/size open |
| Toolhead MCU | BIGTREETECH EBB36 Gen2 | Frozen; purchased |
| Generation 3 extruder/hotend | E3D Roto + Revo, 1.75 mm, direct drive | Frozen architecture; current purchase preference Roto Sensored + Revo 24 V / 40 W |
| Primary material target | PLA, quality-first tuning | Frozen design intent |
| ABS/ASA target | occasional open-frame use only; no heated-chamber requirement | Frozen design intent |
| Z / bed probe | BIGTREETECH Eddy Duo eddy-current probe for fast/dense bed scanning | Frozen architecture; 5 V CAN node after EBB36 passthrough; exact mount/harness to finalise |
| Toolhead network | CAN bus | Frozen |
| CAN distribution | BIGTREETECH CEB V1.0 in electronics bay | Frozen; Generation 3 CAN backbone/distribution point for EBB36/Eddy, Revival Bed Node and RASS CAN Node |
| Historical mechanical skeleton | original flat steel frame + 2× M10×350 mm longitudinal threaded rods + 4× M8×200 mm transverse threaded rods | Frozen; retained as functional final structure |
| X guidance | 1× MGN12-class rail, long MGN12H-class carriage preferred | Frozen architecture |
| X rail support | commercial aluminium T-slot extrusion used as the structural X beam; 2020/2040-class family to be evaluated | Frozen concept; exact section deferred |
| Y guidance | 2× MGN12-class rails, master/slave datum strategy | Frozen architecture |
| Y rail support | 2× longitudinal commercial aluminium T-slot extrusion carriers mounted to the historical M8/M10 base through adjustable interfaces | Frozen concept; exact 2020/2040-class section deferred |
| Z guidance | 2× MGN12-class rails, primary/secondary datum strategy | Frozen architecture |
| Z rail support hierarchy | direct to steel frame if metrology permits; thin aluminium backing plate second; T-slot extrusion only if necessary | Frozen hierarchy; final implementation measurement-dependent |
| Linear-rail alignment | metallic reference surfaces, controlled adjustment/shimming as required, and independent structural locking; rails are never forced to compensate for support error | Frozen architecture |
| X/Y drive | GT2 belt drive | Frozen architecture |
| Z drive | 2× independent Tr8 lead screws and independent Z motors | Frozen architecture |
| Z geometry rule | rails define Z motion; lead screws provide vertical drive only | Frozen |
| Toolhead accelerometer | permanent LIS2DW associated with EBB36 Gen2 | Frozen |
| Initial bed accelerometer | BIGTREETECH S2DW V1.0 (RP2040 + LIS2DW) or equivalent USB solution before Bed Node | Transitional implementation |
| Final bed node | Custom Revival Bed Node, CAN-primary secondary Klipper MCU with USB-C service/fallback, integrated bed sensing/accelerometers and local heater control | Frozen architecture |
| Final bed accelerometer | Remote LIS2DW-class IMU daughterboard on moving bed, connected to Bed Node | Frozen architecture; exact part/link open |
| Bed Node chassis accelerometer | LIS2DW-class IMU on fixed Bed Node PCB | Frozen architecture; structural diagnostics |
| Frame-top accelerometer | Remote LIS2DW-class IMU near top of original flat steel frame, connected to Bed Node | Frozen architecture; long-link implementation open |
| Under-bed status lighting | 24 V RGB strip driven by Bed Node PWM/MOSFET outputs | Frozen architecture; exact strip/current/routing open |
| Bed-node link | CAN through CEB V1.0 for normal runtime; USB-C retained for first flash, recovery, bench diagnostics and optional alternate runtime | Frozen |
| Bed Node telemetry | heater current / 24 V telemetry / secondary temperature / PCB temperature channels | Frozen capability; exact sensors open |
| Smart spool system | Revival-native RFID/NFC identification with local inventory/profile mapping | Frozen architecture |
| Open smart-spool interoperability | OpenPrintTag read compatibility in the target decoder layer | Frozen architecture |
| Bambu spool compatibility | read/import supported original Bambu RFID spool data and translate to Revival model/profile | Frozen architecture |
| Additional vendor compatibility | decoder/plugin framework; Creality smart-spool RFID is a planned validation target | Frozen architecture |
| Unknown-tag learning | fingerprint readable unknown tags, allow assisted manual identification, save samples/signatures and promote validated mappings into new decoders | Frozen architecture |
| Brand database growth | create/update local brands, products, materials, spool families and tag signatures from user-confirmed observations | Frozen architecture |
| Spool weighing | integrated load cell under spool-holder load path; remaining mass = gross mass − tare | Frozen architecture |
| Spool measurement policy | stable weight readings are authoritative; dynamic printing readings are filtered/secondary | Frozen |
| Smart spool RFID path | RFID/NFC reader interfaced by RASS CAN Node; low-level tag observations forwarded to Linux host; CB1 decodes during bench work and CB2 in final build | Frozen architecture; exact CAN/Klipper host transport/API open |
| RASS active feed | single-spool active feeder near spool + driven-spool assistance | Frozen architecture |
| RASS controller | Custom Klipper-compatible CAN node designed for Revival | Frozen architecture; normal runtime via CEB V1.0; exact MCU/transceiver/drivers open |
| Custom-node MCU firmware | Bed Node and RASS Node use unmodified upstream Klipper MCU firmware | Frozen; no private Revival MCU fork or custom C command in production baseline |
| Custom-node expansion exposure | Every electrically usable MCU pin left unassigned after frozen functions is physically exposed and documented, including available SPI/I2C/UART/ADC/GPIO/PWM alternate functions | Frozen; see common custom-node design rules |
| RASS control hierarchy | toolhead direct drive remains extrusion master; RASS follows via buffer/dancer feedback | Frozen |
| RASS tension decoupling | intermediate buffer/dancer between upstream feeder and toolhead | Frozen architecture |
| RASS fallback | passive/manual feed path remains possible if active feed subsystem is unavailable | Frozen design requirement |
| Main frame camera | Innomaker U30CAM-4K-S1, Sony IMX415 STARVIS, USB 3.0 UVC; advertised 4K30 / 1080p60 | Frozen selection; purchase/receipt and CB1 bench validation pending |
| Camera styling | custom retro late-1980s/1990s CCTV/video-surveillance enclosure | Frozen concept |
| Main DC voltage | 24 V | Frozen |
| Final PSU target | Mean Well LRS-600-24, 24 V / 25 A / 600 W | Preferred final model; future purchase |
| Temporary/prototype PSU | existing NUOFUWEI S-24-600, 24 V / 25 A / 600 W | Reuse candidate for bench/prototype work; inspect and test before use |
| Heated-bed construction | original footprint; aluminium + silicone heater + magnetic base + flexible PEI sheet | Frozen architecture |
| Initial bed switching | external DC MOSFET controlled by Manta | Transitional implementation before Bed Node |
| Final bed switching | local Bed Node-controlled MOSFET/power stage near the moving bed | Frozen architecture; exact power stage open |
| Bed protection | dedicated fuse + independent thermal fuse | Frozen architecture |
| Frame lighting | dimmable 24 V diffused white work light | Frozen architecture |
| Toolhead lighting | EBB36-controlled nozzle work/status light | Frozen architecture |
| Hotend cooling | 24 V fan with tachometer feedback preferred | Frozen architecture |
| Electronics cooling | large low-RPM temperature-controlled enclosure fan(s) | Frozen architecture |
| Wiring | completely new harnesses | Frozen |

## Possible future upgrades / candidates

These items are intentionally **not frozen**. They are documented so they are evaluated at the correct design stage rather than forgotten.

| Candidate | Concept | Status |
|---|---|---|
| Nozzle camera | tiny camera fixed to toolhead/nozzle for nozzle-centred timelapse; likely USB/UVC and therefore requiring a separate moving USB service to the toolhead | Possible future upgrade only |
| Nozzle-camera styling | miniature retro CCTV/video-surveillance enclosure, not an exposed PCB | Frozen aesthetic if upgrade is adopted |
| Filament motion/jam sensor | encoder/pulse sensor verifies that filament actually moves when extrusion is commanded | Strong candidate; exact sensor/mount open |
| Nozzle cleaning station | compact purge/wipe/brush station integrated near the bed without materially increasing the envelope | Strong candidate; tied to final probe/toolhead |
| Retro physical control panel | physical pause/resume/function controls matching the industrial Revival aesthetic | Candidate |
| Hardware emergency stop | latching hardware safety control independent of Linux/Klipper/CAN/macros | High-priority safety candidate |
| Maintenance telemetry | runtime, heater/fan cycles, filament throughput, maintenance dates, error history and resonance trends | Candidate; mainly software |
| Electrical monitoring | 24 V voltage/current/power/energy and thermal warm-up trend logging for diagnostics | Candidate; non-safety telemetry |
| Automated pre-print self-check | orchestration of spool ID/weight, filament motion, homing, Z alignment, nozzle clean, bed scan and fan/temperature checks | Candidate after underlying hardware is validated |

The nozzle camera is deliberately excluded from the base moving-harness design until cable flexibility, bend life, strain relief, toolhead mass, EMI and USB topology can be evaluated on the final head.

See [`generation-3-enhancement-candidates.md`](generation-3-enhancement-candidates.md) for evaluation criteria, safety boundaries and the intended relationship between these candidates.

## Selections intentionally deferred

These items must fit the frozen architecture but their exact model or rating depends on later measurement/CAD/testing:

- exact E3D Roto/Revo SKU/revision and final toolhead CAD after fit/thermal review;
- exact Eddy Duo mounting geometry, offset, thermal compensation/calibration strategy and final CAN harness/connector implementation;
- filament-presence / filament-motion sensing implementation;
- exact MGN rail manufacturer, preload class and lengths;
- exact X/Y T-slot extrusion section, orientation, supplier and length; 2020/2040-class profiles remain the design candidates;
- exact profile-to-historical-base bracket geometry and adjustment method;
- whether final Z rails mount directly to the steel frame, use thin aluminium backing plates or require T-slot profiles, as determined by restored-frame metrology;
- exact Z backing-plate/profile dimensions if required;
- exact shim/adjuster screw size/count and final adjustment range;
- exact Y carriage count if testing shows one long carriage per rail is insufficient;
- exact Tr8 lead (Tr8×2 and Tr8×4 remain candidates);
- exact Z motor, nut and upper-support adjustment geometry;
- exact RFID/NFC reader IC and antenna geometry;
- exact Revival tag technology/schema and degree of OpenPrintTag interoperability;
- exact smart-spool reader/controller implementation for RFID/NFC and inventory services;
- exact RASS CAN-node MCU, transceiver/protection, motor drivers, connectors and boot/recovery interface, while exposing every remaining electrically usable MCU pin;
- exact load-cell type, rating, ADC and mechanical mounting arrangement;
- exact smart-spool database/service implementation, on-disk decoder format and UI integration;
- exact RASS local touchscreen model/size, serial/USB host interface and enclosure;
- exact list of additional vendor decoders after real-tag validation;
- exact bed aluminium thickness;
- exact Revival Bed Node MCU, accelerometer, MOSFET/gate driver, connectors, PCB layout, diagnostics and Klipper pin map, while exposing every remaining electrically usable MCU pin;
- exact silicone-heater dimensions and power, after measuring the original heated-bed PCB;
- exact PSU purchase timing after final heater-load confirmation; **Mean Well LRS-600-24 (24 V / 25 A / 600 W)** is the preferred final PSU model;
- fan makes/models and final duct geometry;
- frame-light strip/diffuser;
- connector families and wire gauges;
- final electronics enclosure and airflow geometry;
- main frame-camera physical mount position, framing, focus and validated runtime mode after U30CAM-4K-S1 bench tests;
- optional nozzle-camera hardware/interface if that future upgrade is adopted;
- exact emergency-stop power-cut topology and physical controls;
- exact electrical-monitoring sensor topology;
- exact nozzle-cleaning mechanism and placement.

## Bed size rule

Do not order a 220/235/250 mm standard modern bed merely because it is convenient. The Generation 3 bed is to match the **original heated-bed footprint and travel envelope**. The catalogued approximately 220 × 220 mm Y carriage and 200 × 200 mm original mirror surfaces are reference evidence only; the original heated-bed PCB must be measured before releasing the final aluminium/heater CAD.

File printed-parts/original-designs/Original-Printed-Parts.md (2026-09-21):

---
type: catalogue
area: mechanics
status: under-study
phase: stage-02
priority: high
generation: original
updated: 2026-09-19
---

# Original Printed Parts

[Archive](README.md) · [Small extruder gear](Small-Extruder-Gear.md) · [Provenance](Provenance.md) · [Build phases](../../docs/knowledge-base/build/Build.md)

This catalogue maps historical design files to assembly roles. Quantities describe the conventional assembly, not a new physical inventory. `Visual candidate` means the published shape agrees with visible evidence but dimensions and fit remain unchecked. `Family reference` means a relevant original design without an established match to the recovered part. No item is marked fit-tested.

## X, Y and Z structure

These STL files come from the historical [Clone Wars single-frame collection](https://github.com/Obijuan/Clone-wars/tree/b0bf2cafcef9b367e14d01f21bb3a408e5ffa054/Printers/Prusa3/Single_frame). They complement the archived Josef Prusa sources. The collection is not a modern MK2/MK3/MK4 or a P3Steel set.

| Part / phase | Published STL | Conventional quantity | Match and checks |
| --- | --- | --- | --- |
| Y corners / A–B | [y-corners.stl](upstream/clone-wars/Printers/Prusa3/Single_frame/y-corners.stl) | 4 | Family reference; check M10 longitudinal rods, M8 cross-rods and 8 mm smooth-rod seats against recovered corners. |
| Y motor bracket / C | [y-motor.stl](upstream/clone-wars/Printers/Prusa3/Single_frame/y-motor.stl) | 1 | Family reference; [three-hole alternative](upstream/clone-wars/Printers/Prusa3/Single_frame/Extras/y-motor.stl) is also archived. Compare mounting holes and belt line. |
| Y idler / C | [y-idler.stl](upstream/clone-wars/Printers/Prusa3/Single_frame/y-idler.stl) | 1 | Family reference; verify bearing, axle diameter and clearance. |
| Y belt holder / C | [y-belt-holder.stl](upstream/clone-wars/Printers/Prusa3/Single_frame/y-belt-holder.stl) | 1 | Family reference; compare tooth pitch with the original T2.5 belt and carriage mounting. |
| Z lower motor mounts / E | [z-axis-bottom.stl](upstream/clone-wars/Printers/Prusa3/Single_frame/z-axis-bottom.stl) | 1 plate containing both sides | Family reference; inspect the two objects, frame holes and motor/rod alignment before printing. |
| Z upper rod holders / G | [z-axis-top.stl](upstream/clone-wars/Printers/Prusa3/Single_frame/z-axis-top.stl) | 1 plate containing both sides | Visual candidate: open rod seat and two recessed frame fasteners resemble [TD-102](../../photos/02-teardown/originals/TD-20260913-102-red-printed-structural-part-01.jpg). Measure hole spacing and rod offset. |
| X end, motor side / F | [x-end-motor.stl](upstream/clone-wars/Printers/Prusa3/Single_frame/x-end-motor.stl) | 1 | Family reference; check LM8UU seats, 45 mm rod spacing, Z nut location and motor plate. |
| X end, idler side / F | [x-end-idler.stl](upstream/clone-wars/Printers/Prusa3/Single_frame/x-end-idler.stl) | 1 | Visual candidate: split vertical bearing sleeve and nut seat resemble [TD-073](../../photos/02-teardown/originals/TD-20260913-073-red-printed-part-05.jpg). Verify bearing/axle sizes and rod spacing. |
| X carriage / F–H | [x-carriage.stl](upstream/clone-wars/Printers/Prusa3/Single_frame/x-carriage.stl) | 1 | Family reference; compare with the [V2 alternative](upstream/clone-wars/Printers/Prusa3/Single_frame/x-carriageV2.stl). Do not choose by filename alone: compare extruder mounting and T2.5 belt attachment. |
| Jonas extruder adapter / H | [jonas_mount_i3.stl](upstream/clone-wars/Printers/Prusa3/Single_frame/Extras/jonas_mount_i3.stl) | As required by selected carriage | Family reference; the presence of this adapter in the archive does not prove it was fitted to this printer. |

## Greg/Wade extrusion

The following files were downloaded directly from [Jonas Kühling's Thingiverse publication 18379](https://www.thingiverse.com/thing:18379). Both metric gear files are also byte-identical to those in the historical Clone Wars mirror. The author specifies a **9-tooth small / 47-tooth large herringbone pair**.

| Part / phase | Published file | Match and checks |
| --- | --- | --- |
| Small motor gear / H | [smallgearmod_fixed.stl](upstream/jonaskuehling-18379/files/smallgearmod_fixed.stl) | Candidate companion to the matching large-gear design. Use the [small-gear page](Small-Extruder-Gear.md) before selecting the print. |
| Large hobbed-bolt gear / H | [biggearmod_fixed.stl](upstream/jonaskuehling-18379/files/biggearmod_fixed.stl) | Strong visual candidate: five circular lightening holes, central nut trap and herringbone teeth agree with [TD-078](../../photos/02-teardown/originals/TD-20260913-078-extruder-large-gear-front.jpg), [TD-079](../../photos/02-teardown/originals/TD-20260913-079-extruder-large-gear-rear.jpg) and [TD-080](../../photos/02-teardown/originals/TD-20260913-080-extruder-large-gear-edge.jpg). Tooth count and dimensions still need physical confirmation. |
| Hinged idler / H | [jonaskuehling_gregs-wade-v3_idler-only.stl](upstream/jonaskuehling-18379/files/jonaskuehling_gregs-wade-v3_idler-only.stl) | Strong visual candidate: the guided bearing window, hinge and open tension-screw slots resemble [TD-069](../../photos/02-teardown/originals/TD-20260913-069-red-printed-part-01.jpg). Check bearing and pivot dimensions. |
| Extruder body / H | [J-head body-only plate](upstream/jonaskuehling-18379/files/jonaskuehling_gregs-wade-v3_jhead-BODY-ONLY.stl) | Family reference with the curved motor mount seen in [TD-025](../../photos/02-teardown/originals/TD-20260913-025-extruder-gears-detail.jpg). This file also contains a loose washer. The recovered E3D-family groove mount is not identified by the J-head filename. Compare mounting holes and hotend seat before selection. |
| Alternative hotend interfaces / H | [Groovemount](upstream/jonaskuehling-18379/files/jonaskuehling_gregs-wade-v3_groovemount.stl), [J-head](upstream/jonaskuehling-18379/files/jonaskuehling_gregs-wade-v3_jhead.stl), [reprapfaborg](upstream/jonaskuehling-18379/files/jonaskuehling_gregs-wade-v3_reprapfaborg.stl) | Original author variants; these are alternatives, not three installed extruders. Inspect each plate's objects and sacrificial support geometry. |
| Historical layer-specific export / H | [J-head LAYER-0-35](upstream/jonaskuehling-18379/files/jonaskuehling_gregs-wade-v3_jhead-LAYER-0-35.stl) | Alternative export; author notes tie support membranes to layer thickness. This is not a P1S profile. |
| Non-default gear and imperial variants | [4.2 mm small gear](upstream/jonaskuehling-18379/files/small-gear-mod_holedia-4-2.stl), [SAE large gear](upstream/jonaskuehling-18379/files/big-gear-mod_SAE.stl), [SAE body](upstream/jonaskuehling-18379/files/jonaskuehling_gregs-wade-v3_SAE_groovemount.stl) | Preserved to keep the author's file set complete. These are not the default candidates for this metric machine. |

Editable body sources and their dependencies are in [the original SCAD entry point](upstream/jonaskuehling-18379/files/jonaskuehling_gregs-wade-v3.scad). This package does **not** contain editable source for the exact two gear meshes; the original STLs are preserved instead.

## Auxiliary parts and coverage gaps

| Role | Archived source or evidence | Remaining work |
| --- | --- | --- |
| Belt bearing guides / C–F | [Original belt-guide SCAD](upstream/josefprusa-prusa3/old_single_plate/src/belt-guide.scad) | Source archived; export the measured bearing/axle variant separately if needed. |
| Fan mount | [Original fan-mount SCAD](upstream/josefprusa-prusa3/old_single_plate/src/fan-mount.scad) | Family reference only. This does not identify the recovered hotend's fan duct. |
| Magnetic endstop holder | [Original magnetic-holder SCAD](upstream/josefprusa-prusa3/old_single_plate/src/magnetic-holder.scad) | Historical alternative; do not substitute it for the recovered mechanical-switch arrangement. |
| Mechanical endstop clamps / I | [Endstop-holder SCAD](upstream/josefprusa-prusa3/box_frame/extras/endstop-holder.scad), [90-degree adapter SCAD](upstream/josefprusa-prusa3/box_frame/extras/endstop-holder-extra.scad) | Original family sources archived; match clamp diameter, PCB hole pitch and actuation geometry to the actual holders before creating an export. |
| Hotend-specific clamp/duct | [Installed extruder evidence](../../photos/02-teardown/originals/TD-20260913-025-extruder-gears-detail.jpg) and [legacy hotend identification](../../docs/knowledge-base/systems/Extrusion.md) | Exact original variant remains unresolved. The Rework Magma body/duct must not be presented as an E3D replacement. |
| Loose black brackets and blocks / A–J | [Original teardown index](../../photos/02-teardown/INDEX.md), especially TD-081–101 and TD-113–114 | Attribution and installed-versus-spare status require individual matching. Similarity to a motor bracket is not enough to assign every loose piece to the original build. |

All 12 STL files in the selected Clone Wars single-frame directory and all 17 design files in Jonas's publication are present. That completes those **published file sets**, while the exact physical-part inventory remains open for the auxiliary pieces above. Record measurements and successful fit against the part's existing inventory entry; do not rename historical photo IDs.

For Bambu Studio, start from the linked STL at 100% scale, inspect the objects and dimensions, and use the P1S with the actual filament loaded in that printer. The Revival's legacy 3 mm filament path is a property of the part being reproduced, not the P1S filament setting. Follow the [Stage 02 replacement policy](../../docs/02-reassembly/README.md#temporary-replacement-parts-during-reassembly).

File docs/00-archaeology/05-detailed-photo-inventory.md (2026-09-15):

# Detailed photo inventory — ARQ archaeology archive

**Primary capture date:** 12 September 2026  
**Detailed coverage:** ARQ-20260912-001 through ARQ-20260912-072, plus ARQ-20260915-081 through ARQ-20260915-089  
**Archive:** `photos/00-archaeology/originals/`

This is the per-image archaeology index. Each permanent photo ID records what is visible, the current identification, documentary value, and the most useful next action. Identifications marked provisional must be confirmed by teardown, labels, measurement or bench testing.

Photographs 073–080 are preserved in the archive and are pending expansion of this detailed table. Photographs 081–089 document the recovered motion-electronics spare box found on 15 September 2026.

## Action vocabulary

- **REFERENCE** — preserve as evidence of original configuration or context.
- **IDENTIFY** — obtain labels/measurements before assigning an exact model.
- **MEASURE** — dimensions/electrical characteristics are needed.
- **TEST** — bench-test before reuse.
- **REUSE CANDIDATE** — potentially useful in the Revival.
- **RESTORE** — worth cleaning/repairing before evaluation.
- **ARCHIVE** — primarily historical/documentary value.
- **BLOG** — useful source image for the future build story.

## Per-photo inventory

| ID | Contents / current identification | Provenance | Potential utility | Action |
|---|---|---|---|---|
| 001 | Printer as found, oblique overall view in storage area | PRINTER-AS-FOUND | Baseline condition and geometry before intervention | REFERENCE, BLOG |
| 002 | Printer as found, second overall view showing frame, bed and carriage | PRINTER-AS-FOUND | Baseline assembly/layout comparison after restoration | REFERENCE, BLOG |
| 003 | Wider storage context with printer and surrounding boxes/material | PRINTER-AS-FOUND | Provenance/context for archaeology story | ARCHIVE, BLOG |
| 004 | Wider storage context from another angle | PRINTER-AS-FOUND | Documents recovery environment before removal | ARCHIVE, BLOG |
| 005 | Printer overall view, frame and carriage visible | PRINTER-AS-FOUND | Baseline mechanical configuration | REFERENCE, BLOG |
| 006 | Complete printer on work surface after recovery | PRINTER-AS-FOUND | Strong general reference for original routing and layout | REFERENCE, BLOG |
| 007 | Printer oblique view with LCD/controller and carriage visible | PRINTER-AS-FOUND | Documents display placement and wiring/layout | REFERENCE |
| 008 | Wade/Greg's-Wade-family geared extruder, close view | PRINTER-AS-FOUND | Phase-1 Legacy 3 mm extruder reconstruction reference | IDENTIFY, REUSE CANDIDATE |
| 009 | Extruder/hotend carriage from opposite angle | PRINTER-AS-FOUND | Documents mounting, fan/hotend relationship and printed parts | REFERENCE, IDENTIFY |
| 010 | Z motor and flexible aluminium coupler close-up | PRINTER-AS-FOUND | Reference for original Z drive; useful when selecting leadscrew replacement | MEASURE, BLOG |
| 011 | Second Z motor/coupler close-up | PRINTER-AS-FOUND | Confirms dual-Z arrangement and original coupling geometry | MEASURE |
| 012 | Installed 12864-style graphic LCD/controller | PRINTER-AS-FOUND | Historical UI reference; possible bench-test spare | TEST, ARCHIVE |
| 013 | Installed Mega/RAMPS-era electronics and wiring close-up | PRINTER-AS-FOUND | Critical evidence for original controller topology and cable routing | IDENTIFY, REFERENCE |
| 014 | Installed plug-in stepper-driver area with blue heatsinks | PRINTER-AS-FOUND | Driver count/orientation and historical electronics evidence | IDENTIFY, REFERENCE |
| 015 | Rear/side electronics and wiring view | PRINTER-AS-FOUND | Reconstruct original wiring topology before dismantling | REFERENCE |
| 016 | Extruder/hotend carriage detail | PRINTER-AS-FOUND | Mounting geometry and Legacy 3 mm toolhead documentation | IDENTIFY, REFERENCE |
| 017 | Y-axis threaded-rod base detail, feet/nuts/smooth guide visible | PRINTER-AS-FOUND | Essential geometry reference for mechanical rebuild | MEASURE, BLOG |
| 018 | Y-axis base detail from near-identical second angle | PRINTER-AS-FOUND | Redundant geometry evidence useful during teardown | MEASURE |
| 019 | Y-axis base detail, additional view | PRINTER-AS-FOUND | Confirms threaded-rod construction and spacing | MEASURE |
| 020 | E3D-family hotend heatsink beside geared extruder | PRINTER-AS-FOUND | Identify exact V5/V6-era hotend and 3 mm configuration | IDENTIFY, REUSE CANDIDATE |
| 021 | Installed cooling fan close-up | PRINTER-AS-FOUND | Determine fan size/voltage and original cooling arrangement | IDENTIFY, MEASURE |
| 022 | Old print/build-surface sheets or adhesive films | LOOSE-FOUND | Historical consumable evidence; possible material comparison | ARCHIVE |
| 023 | Loose heater cartridge with red high-temperature leads | LOOSE-FOUND | Possible hotend spare if voltage/power/resistance are verified | MEASURE, TEST |
| 024 | Same heater cartridge in labelled bag | LOOSE-FOUND | Label/provenance evidence for heater identification | IDENTIFY, ARCHIVE |
| 025 | Small boxed period component; exact identity not established visually | LOOSE-FOUND | Preserve until package/markings can be read | IDENTIFY |
| 026 | Coiled multi-core cable | LOOSE-FOUND | Potential sensor/motor wiring stock | IDENTIFY, TEST |
| 027 | Stripped end of multi-core cable showing conductors/shielding | LOOSE-FOUND | Determine conductor count/gauge and suitability for rewiring | MEASURE, TEST |
| 028 | Cable loom/extensions with connectors | LOOSE-FOUND | Possible motor/sensor extension harness | IDENTIFY, TEST |
| 029 | Loom with original physical label `MOTOR EJE E0` | LOOSE-FOUND | Strong provenance clue for extruder-motor wiring; label preserved verbatim | REFERENCE, TEST |
| 030 | Mechanical endstop module with cable | LOOSE-FOUND | Possible spare endstop for bench/original-style restoration | TEST, REUSE CANDIDATE |
| 031 | Loose NEMA17 stepper with harness | LOOSE-FOUND | Spare motor candidate after electrical/mechanical checks | IDENTIFY, TEST |
| 032 | Longs NEMA17 stepper, label visible (17HS8401S1 recorded) | LOOSE-FOUND | Known spare motor candidate; compare torque/current with Revival needs | TEST, REUSE CANDIDATE |
| 033 | Additional coiled wiring/harness | LOOSE-FOUND | Potential rewiring stock or historical harness | IDENTIFY, TEST |
| 034 | Additional wiring/harness view | LOOSE-FOUND | Connector and conductor inventory | IDENTIFY |
| 035 | Black braided cable sleeving/loom | LOOSE-FOUND | Potential cable-management reuse if condition is good | INSPECT, REUSE CANDIDATE |
| 036 | Close-up of black braided sleeving | LOOSE-FOUND | Assess diameter, wear and suitability for harness restoration | MEASURE, INSPECT |
| 037 | Small controller/display-related PCB, rear/label side | LOOSE-FOUND | Exact identification and possible historical interface use | IDENTIFY |
| 038 | Arduino-class board with prototyping/perfboard shield | LOOSE-FOUND / PERIOD-UNRELATED | General bench/prototyping hardware, not attributed to printer | TEST, ARCHIVE |
| 039 | Loose 5-inch LCD panel, front view | LOOSE-FOUND | Documents display condition; likely associated with later Raspberry Pi hardware | IDENTIFY, ARCHIVE |
| 040 | Same LCD assembly, edge/connector profile | LOOSE-FOUND | Mechanical/interface identification | IDENTIFY |
| 041 | Raspberry Pi 2 + Waveshare 5inch HDMI LCD V2 rear electronics | LOOSE-FOUND | Period control/display experiment; Pi may remain reusable | TEST, ARCHIVE |
| 042 | Raspberry Pi 2 + Waveshare display, second rear view | LOOSE-FOUND | Connector and mounting documentation | TEST, ARCHIVE |
| 043 | Raspberry Pi 2 with damaged Waveshare display, separated view | LOOSE-FOUND | Pi reuse candidate; display useful mainly as historical evidence/parts | TEST, ARCHIVE |
| 044 | Alhambra II Open FPGA Board material/documentation | PERIOD-UNRELATED | Historical electronics; no confirmed printer relationship | ARCHIVE |
| 045 | Box/batch of old printed mechanical parts | DONATED-PURCHASED | Provenance for period RepRap parts collection | IDENTIFY, BLOG |
| 046 | Spread of red/black printed parts, gears, washers and brackets | DONATED-PURCHASED | Candidate donor parts; useful for identifying period designs | IDENTIFY, ARCHIVE |
| 047 | Closer subset: large gear, brackets, washers and small parts | DONATED-PURCHASED | Individual part identification and dimensional comparison | IDENTIFY |
| 048 | Similar printed-parts subset from another angle | DONATED-PURCHASED | Cross-reference for geometry and condition | IDENTIFY |
| 049 | Close-up of large printed gear and red structural pieces | DONATED-PURCHASED | Compare gear geometry with Wade-family extruder parts | MEASURE, IDENTIFY |
| 050 | Close-up of black printed duct/housing/bracket pieces | DONATED-PURCHASED | Possible fan/toolhead components; exact design pending | IDENTIFY |
| 051 | Close-up of black printed components among red donor parts | DONATED-PURCHASED | Possible toolhead/fan components; preserve for matching | IDENTIFY |
| 052 | Assorted loose cooling fans of several sizes | LOOSE-FOUND | Possible enclosure/electronics/part-cooling spares after voltage and bearing tests | IDENTIFY, TEST |
| 053 | Five small aluminium/black heatsinks, one with thermal pad | LOOSE-FOUND | Driver/electronics thermal-management spares | INSPECT, REUSE CANDIDATE |
| 054 | Mixed period electronics: LCDs, Arduino-class boards and RAMPS-style hardware | LOOSE-FOUND / PERIOD-UNRELATED | Overview inventory; useful for matching boards to later close-ups | IDENTIFY, ARCHIVE |
| 055 | Closer overview of LCD modules and Arduino/Ethernet-capable boards | LOOSE-FOUND / PERIOD-UNRELATED | Candidate bench electronics; establish exact models individually | IDENTIFY, TEST |
| 056 | Assorted aluminium/copper/black heatsinks | LOOSE-FOUND | Potential driver/SBC cooling hardware | INSPECT, REUSE CANDIDATE |
| 057 | Small Ethernet interface module with RJ45 jack | LOOSE-FOUND | Possible network interface for period controller project; exact chipset/use pending | IDENTIFY, TEST |
| 058 | Bag of multiple heater cartridges/high-temperature red leads | LOOSE-FOUND | Useful hotend spares if dimensions, voltage and wattage match | MEASURE, TEST, REUSE CANDIDATE |
| 059 | RAMPS 1.4sb shield, component side | LOOSE-FOUND | Candidate companion shield for Re-ARM; power stages/connectors require inspection | TEST, REUSE CANDIDATE |
| 060 | Panucatt Devices Re-ARM, component side | LOOSE-FOUND | Important 32-bit historical upgrade candidate for Revival controller | TEST, REUSE CANDIDATE, BLOG |
| 061 | Panucatt Devices Re-ARM, solder/rear side | LOOSE-FOUND | Board-condition and revision evidence before power-up | INSPECT, TEST |
| 062 | RAMPS 1.4sb, component side close-up | LOOSE-FOUND | Inspect MOSFETs, terminals, fuses, sockets and driver headers | INSPECT, TEST |
| 063 | RAMPS 1.4sb, solder/rear side | LOOSE-FOUND | Check solder joints, overheating and board damage | INSPECT, TEST |
| 064 | Reflective amber/copper-coloured film/sheet | LOOSE-FOUND | Exact material/use unknown; possible thermal/insulation material | IDENTIFY, ARCHIVE |
| 065 | Roll of reflective amber/copper-coloured film/tape | LOOSE-FOUND | Possible thermal/electrical tape stock; composition must be identified before reuse | IDENTIFY |
| 066 | Mean Well Q-60B multi-output PSU, label visible (+5/+12/-5/-12 V) | LOOSE-FOUND | Bench/period electronics PSU; not an obvious main printer PSU candidate | TEST, ARCHIVE |
| 067 | Four loose NEMA17 stepper motors, close overview | LOOSE-FOUND | Strong spare-motor pool for Revival after labels/current/shaft checks | IDENTIFY, TEST, REUSE CANDIDATE |
| 068 | Same four NEMA17 motors, wider view | LOOSE-FOUND | Inventory/count and condition reference | IDENTIFY, TEST |
| 069 | Staticboards heated bed, top face with 12/24 V markings | LOOSE-FOUND | Potential replacement/spare bed; dimensions, resistance and flatness need checking | MEASURE, TEST, REUSE CANDIDATE |
| 070 | Heated bed aluminium rear/backing face and cable | LOOSE-FOUND | Inspect wiring, insulation, flatness and mounting pattern | INSPECT, MEASURE |
| 071 | Generic S-360-12 open-frame PSU, label: 12 V / 30 A | LOOSE-FOUND | Possible 12 V printer/bench PSU only after full safety and load testing | TEST, ARCHIVE |
| 072 | Mean Well SP-240-24 open-frame PSU, label: 24 V / 10 A | LOOSE-FOUND | High-interest 24 V PSU candidate for bench/subsystems; capacity vs full Revival load must be calculated | TEST, REUSE CANDIDATE |

| 081 | Mechanical endstop modules, component/front view | LOOSE-FOUND | Spare mechanical limit-switch modules for original-hardware revival | TEST, REUSE CANDIDATE |
| 082 | Mechanical endstop modules, rear/alternate view | LOOSE-FOUND | Connector, PCB and microswitch reference for spare endstops | TEST, REUSE CANDIDATE |
| 083 | DRV8825 stepper-driver module close-up | LOOSE-FOUND | Period motion-control spare; exact carrier condition requires bench test | INSPECT, TEST |
| 084 | DRV8825 stepper-driver module, second close-up | LOOSE-FOUND | Marking/component-layout evidence for recovered DRV8825 stock | INSPECT, TEST |
| 085 | Three A4988 StepStick driver modules | LOOSE-FOUND | Preferred period-style replacement stock if a Generation-1 driver fails | TEST, REUSE CANDIDATE |
| 086 | Recovered stepper-driver group, first overview | LOOSE-FOUND | Inventory and condition reference for motion-electronics spare stock | IDENTIFY, TEST |
| 087 | Recovered stepper-driver group, second overview | LOOSE-FOUND | Confirms quantity/layout of recovered driver modules | IDENTIFY, TEST |
| 088 | Recovered driver group, closer detail | LOOSE-FOUND | Component-marking and potentiometer/orientation reference | INSPECT, TEST |
| 089 | Five StaticBoards TMC2130 StepStick modules | LOOSE-FOUND | Strong Generation-2 experimentation candidate using SPI-capable drivers | TEST, REUSE CANDIDATE, BLOG |

## Notes

The archive deliberately distinguishes **what a photograph proves** from **what we currently suspect**. Loose items are never treated as original printer equipment merely because they were found in the same storage area.

Future catalogue expansion must preserve existing IDs. If an identification changes, update the description/confidence/action but preserve the permanent ARQ ID.

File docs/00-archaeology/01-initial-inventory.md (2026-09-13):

# Initial archaeology inventory

**Original observation date:** 12 September 2026  
**Stage status:** historical Stage 00 baseline; superseded for technical identification by the completed Stage 01 teardown/inventory.

This document records what could be identified visually **before dismantling** the printer. It intentionally preserves the uncertainty that existed at the time. Confirmed teardown findings are recorded separately below rather than rewriting the original observations as if they had been known in advance.

## Original provisional identification

Family: **classic Prusa i3 / Rework-era / RepRap derivative**.

The exact variant was not established during non-invasive archaeology and remains intentionally unclaimed where the evidence does not justify a narrower historical designation.

## What the as-found inspection showed

### Structure
- Flat single-sheet metal vertical frame.
- Y base built from threaded rods, nuts and printed parts.
- Smooth-rod linear guides.

### Z axis
- Two NEMA17 motors.
- Smooth vertical guide rods.
- Conventional threaded rods used for Z motion.
- Flexible aluminium couplers between motors and threaded rods.

### Extruder and hotend
- Direct geared extruder from the Wade / Greg's Wade family.
- Large printed driven gear and motor pinion.
- Spring-loaded idler system.
- Historical configuration for the legacy approximately 3 mm filament system.
- E3D-family hotend visible, exact generation unresolved at Stage 00.

### Electronics
- Mega/RAMPS-era controller architecture.
- Plug-in stepper drivers with heatsinks.
- RepRapDiscount-style full graphic controller.
- Open-frame metal power supply.

### Bed and motion
- Heated bed with removable glass/mirror print surface.
- Four-point screw-and-spring levelling arrangement.
- Toothed-belt X/Y transmission.

## Stage 01 resolution — 13 September 2026

The controlled teardown, cleaning and component inventory resolved most of the Stage 00 questions:

| Subject | Current documented result |
|---|---|
| Controller | **Arduino Mega 2560** |
| Main shield | **StaticBoards RAMPS 1.4SB** |
| Stepper drivers | **4× A4988-family plug-in modules**; exact clone/revision not claimed |
| Installed motors | **5× Wantai 42BYGHW811 NEMA17**, labelled 2.5 A and 1.8°/step |
| Main PSU | **JCPOWER JC-360-12**, 110/220 VAC input, 12 V / 30 A output |
| LCD / storage | RepRapDiscount-style graphic controller + RAMPS smart adapter + Panasonic 16 GB SDHC |
| Y carriage | approximately **220 × 220 mm**, approximately **210 mm hole spacing** in both axes, **6 mm** thick, M3 threaded mounting holes |
| Structural threaded rods | **2× M10 × 350 mm** and **4× M8 × 200 mm** |
| Original Z threaded rods | **2× M5 × 310 mm** |
| Smooth rods | **2× Ø8 × 350 mm**, **2× Ø8 × 330 mm**, **2× Ø8 × 317 mm** |
| Linear bearings | **10× LM8UU-family** |
| Radial bearings | **3× FAG 608Z**, standard 8 × 22 × 7 mm family |
| Belt transmission | **T2.5**, with approximately **20-tooth** aluminium drive pulleys; one documented open belt is approximately 800 mm long |
| Build surfaces | **4× IKEA SÖRLI mirrors**, 200 × 200 × 3 mm |
| Bed levelling | Screw-and-spring system; the improvised clothes-peg springs are preserved and documented |
| Hotend | Legacy **E3D-family**, probably V5-era, for the 3 mm / 2.85 mm stage; exact revision still unconfirmed |
| Hotend sensor | Legacy bead thermistor; likely 100 kΩ class, but exact type remains pending electrical measurement |
| Heater cartridge | Still installed in the heater block; retaining screw head is stripped, so removal was deliberately deferred |
| Wiring | Original mixed wiring harness documented but **not selected for reuse**; the revival will be rewired from scratch |

The original heated-bed PCB, geared extruder and mechanical endstop modules are also documented in the Stage 01 original photo archive.

## Remaining uncertainties

Teardown completion does not justify pretending every exact part number is known. The following remain deliberately open until measurement or bench testing provides evidence:

- exact historical Prusa i3 sub-variant;
- exact E3D hotend generation/revision;
- exact thermistor curve/type;
- exact manufacturer/revision of each A4988-family driver module;
- electrical and mechanical condition of components not yet bench-tested.

## Evidence

Stage 00 evidence remains under `photos/00-archaeology/`.  
Stage 01 teardown and inventory evidence is under `photos/02-teardown/` and currently reaches `TD-20260913-228`.

## Safety rule

Do not power the old electronics until the PSU, mains wiring, heated bed, connectors, insulation and protection arrangements have been inspected. Mechanical reassembly comes before electrical commissioning.

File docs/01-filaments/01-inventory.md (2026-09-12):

# Legacy filament inventory — Batch 01

**Date:** 12 September 2026  
**Source:** recovered stored filament from the original Prusa i3 era  
**Status:** photographic archive uploaded and cross-referenced; visual/label inspection only. No spool has yet been dried or test-printed in the Revival.

> The exact remaining mass of each spool is still unknown. Labels below document the product specification, not the amount currently left.

| ID | Brand / product | Material | Labelled diameter | Colour | Labelled print temperature | Photo evidence | Revival assessment | First action |
|---|---|---|---:|---|---|---|---|---|
| FIL-001 | FFF World FlexiSMART | Flexible TPU | 3.00 mm | Black | handwritten 220–240 °C; box text also gives a broader generic range | [001 label](../../photos/01-filaments/originals/FIL-20260912-001-flexismart-tpu-black-label.jpg), [002 box](../../photos/01-filaments/originals/FIL-20260912-002-flexismart-tpu-black-box-front.jpg) | **Usable candidate.** Direct-drive Wade-style extrusion is favourable, but the feed path must be tightly constrained and speeds kept low. TPU is hygroscopic. | Inspect for tackiness/cracking, dry, measure diameter, then slow extrusion test |
| FIL-002 | FFF World FlexiSMART | Flexible TPU | 3.00 mm | Red | label visible in archive; exact temperature to be confirmed from box | [003 label](../../photos/01-filaments/originals/FIL-20260912-003-flexismart-tpu-red-label.jpg) | **Usable candidate** under the same conditions as FIL-001 | Dry, measure diameter and bench-test |
| FIL-003 | Generic legacy box marked PLA 3.0 mm | PLA | 3.00 mm | White | not yet transcribed | [004 box](../../photos/01-filaments/originals/FIL-20260912-004-pla-3mm-white-box.jpg) | **Conditional candidate.** Old PLA can become very brittle after long storage even when sealed. | Bend/brittleness test, dry gently, measure diameter |
| FIL-004 | T-PLA | PLA-family | 3.00 mm | Violet | not yet transcribed | [005 box](../../photos/01-filaments/originals/FIL-20260912-005-tpla-3mm-violet-box.jpg) | **Conditional candidate.** Treat as old PLA until exact formulation is confirmed. | Inspect, dry gently, measure diameter |
| FIL-005 | ABS-H | Filled/special ABS | 3.00 mm | Glow in the dark green | not yet transcribed | [006 box](../../photos/01-filaments/originals/FIL-20260912-006-absh-3mm-glow-dark-green-box.jpg) | **Usable candidate with caution.** Glow pigments are typically abrasive; avoid using a soft brass nozzle for a large quantity. | Confirm formulation, use hardened nozzle, dry and test |
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

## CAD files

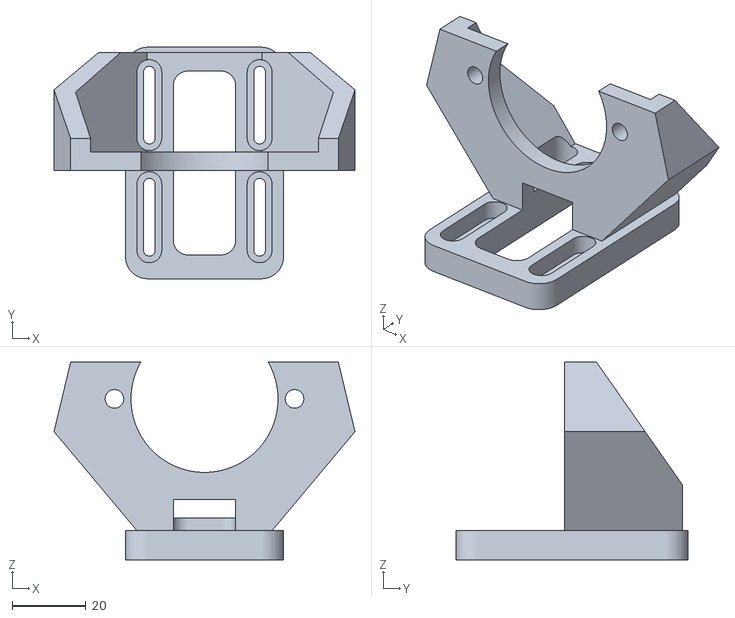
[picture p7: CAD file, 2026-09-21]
printed-parts/original-designs/upstream/clone-wars/Printers/Prusa3/Single_frame/Extras/jonas_mount_i3.stl
81.9 x 63.0 x 53.8

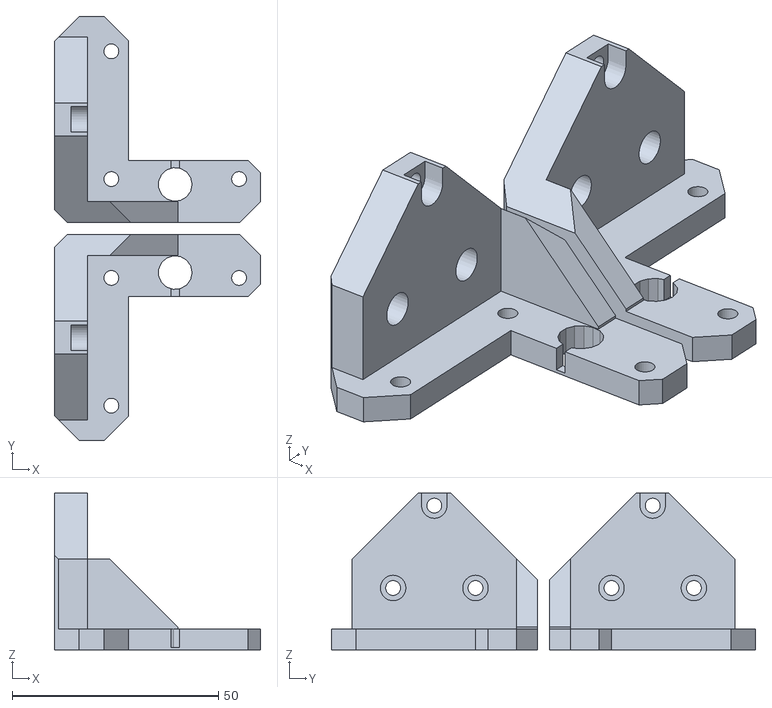
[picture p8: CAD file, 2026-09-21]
printed-parts/original-designs/upstream/clone-wars/Printers/Prusa3/Single_frame/z-axis-bottom.stl
50.0 x 103.0 x 38.0

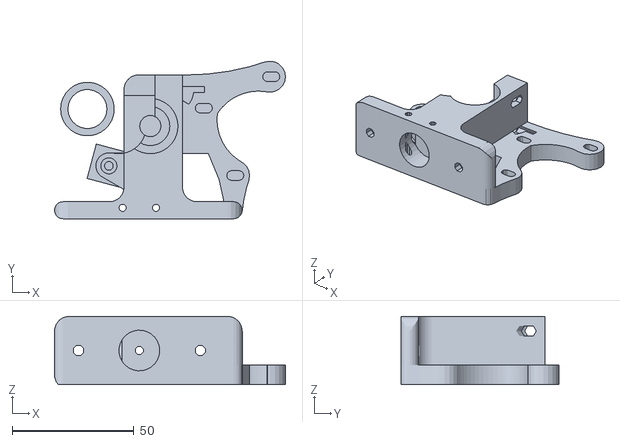
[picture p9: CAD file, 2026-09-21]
printed-parts/original-designs/upstream/jonaskuehling-18379/files/jonaskuehling_gregs-wade-v3_jhead-BODY-ONLY.stl
94.7 x 64.6 x 28.0

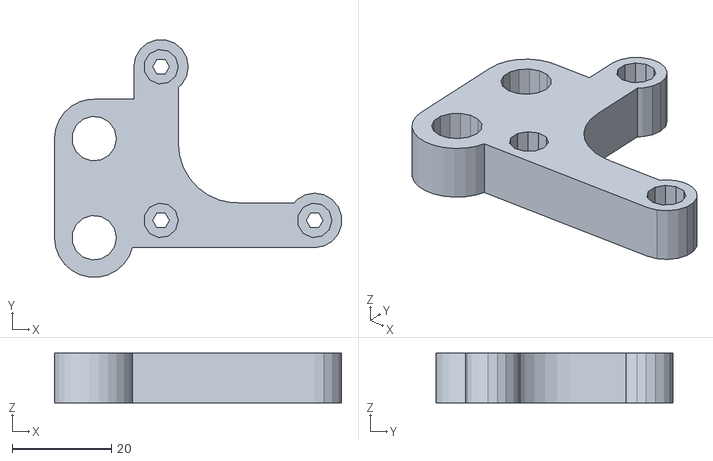
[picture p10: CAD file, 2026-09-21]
printed-parts/original-designs/upstream/clone-wars/Printers/Prusa3/Single_frame/Extras/y-motor.stl
57.9 x 47.9 x 10.0

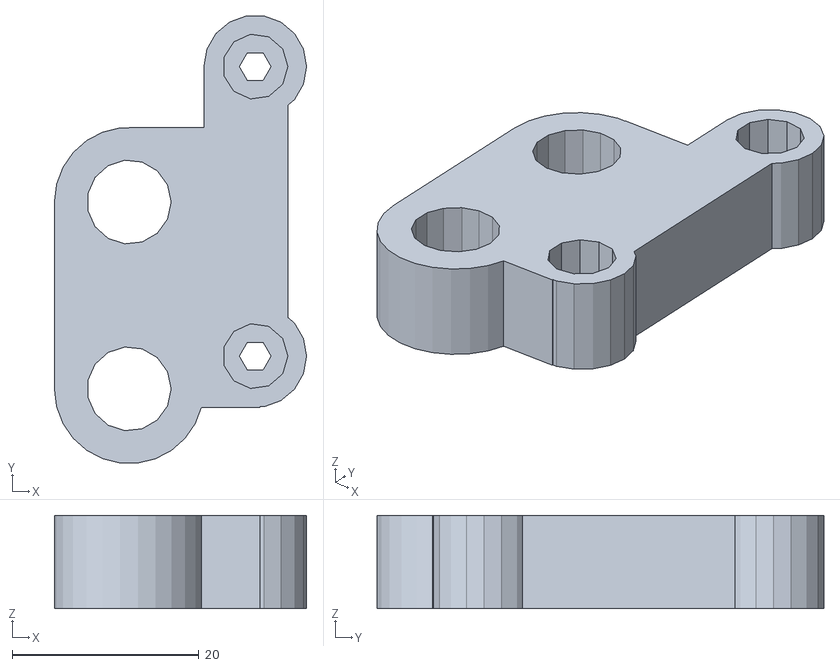
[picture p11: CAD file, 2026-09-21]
printed-parts/original-designs/upstream/clone-wars/Printers/Prusa3/Single_frame/y-motor.stl
27.0 x 47.9 x 10.0

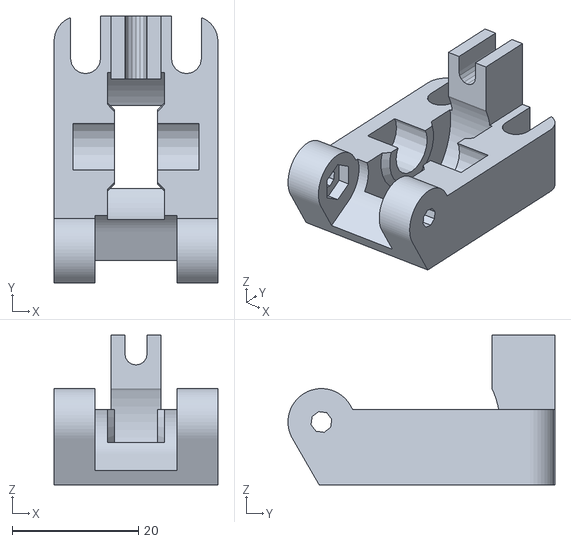
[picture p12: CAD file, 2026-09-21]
printed-parts/original-designs/upstream/jonaskuehling-18379/files/jonaskuehling_gregs-wade-v3_idler-only.stl
26.0 x 42.4 x 23.8

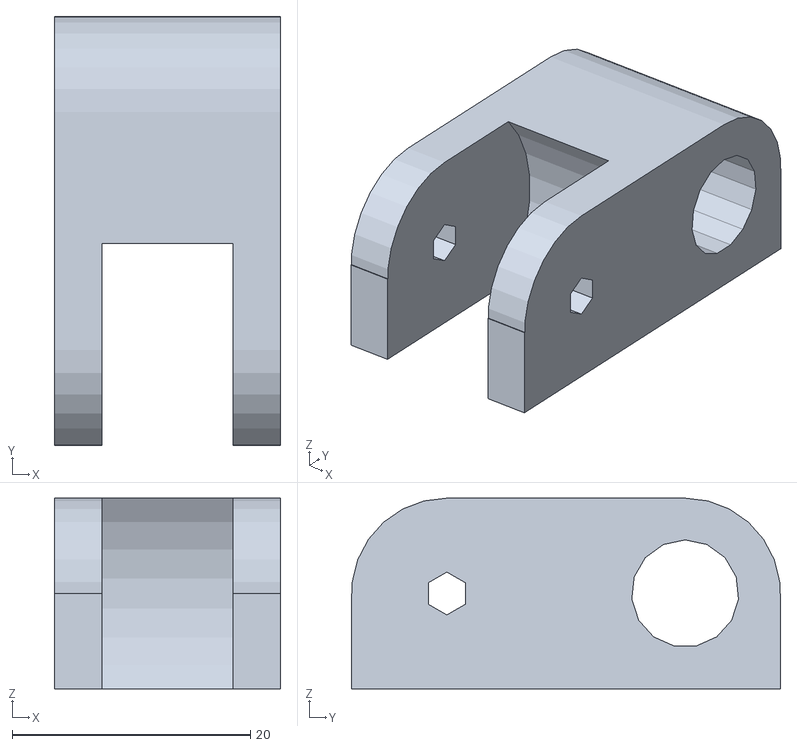
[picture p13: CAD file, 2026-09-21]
printed-parts/original-designs/upstream/clone-wars/Printers/Prusa3/Single_frame/y-idler.stl
19.0 x 36.0 x 16.0

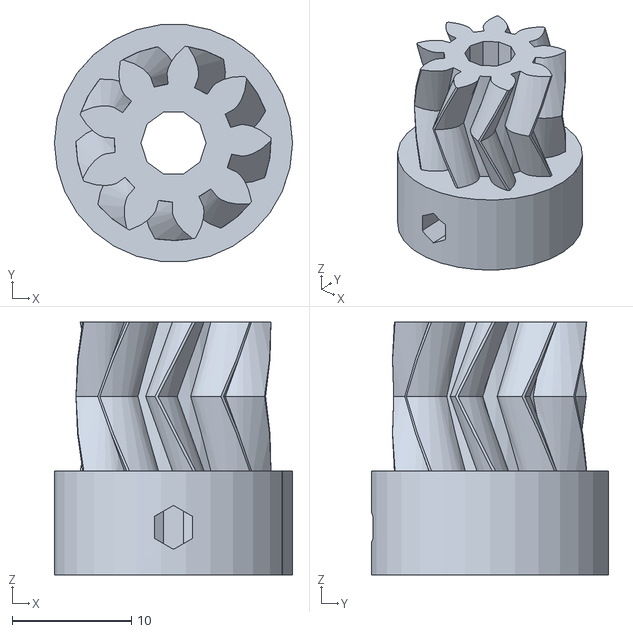
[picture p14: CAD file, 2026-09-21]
printed-parts/original-designs/upstream/jonaskuehling-18379/files/smallgearmod_fixed.stl
20.0 x 19.9 x 21.2

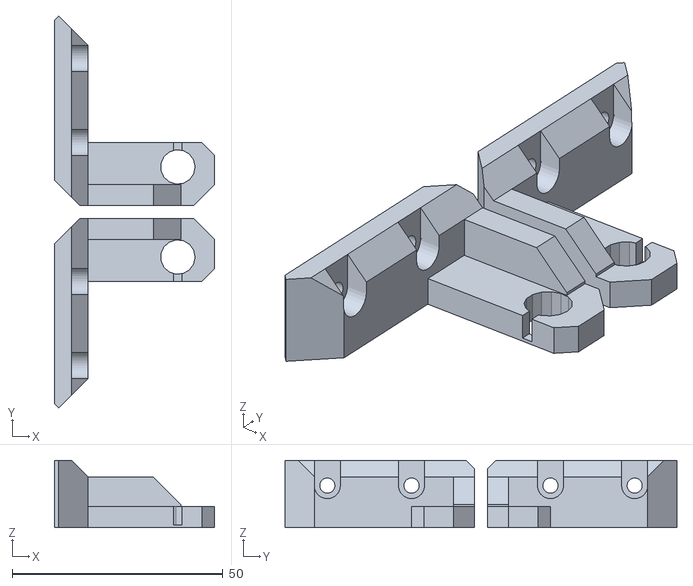
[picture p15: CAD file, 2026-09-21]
printed-parts/original-designs/upstream/clone-wars/Printers/Prusa3/Single_frame/z-axis-top.stl
38.0 x 93.0 x 16.0

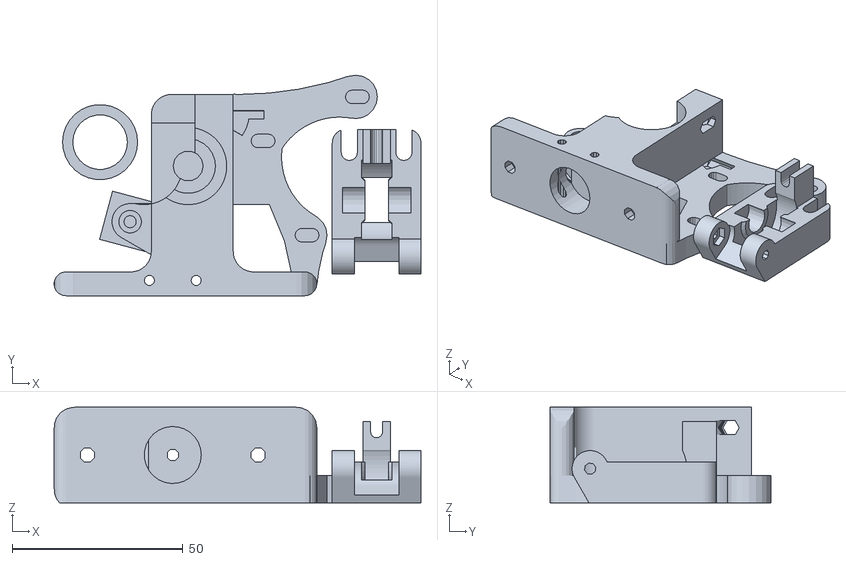
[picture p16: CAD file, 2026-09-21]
printed-parts/original-designs/upstream/jonaskuehling-18379/files/jonaskuehling_gregs-wade-v3_jhead.stl
107.5 x 64.6 x 28.0

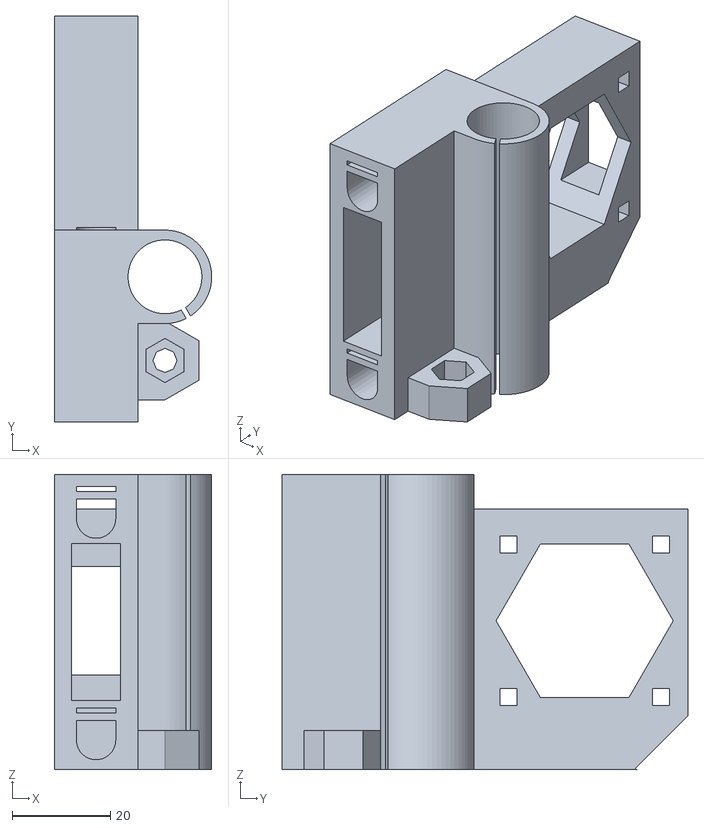
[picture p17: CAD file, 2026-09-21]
printed-parts/original-designs/upstream/clone-wars/Printers/Prusa3/Single_frame/x-end-motor.stl
32.0 x 82.5 x 60.0

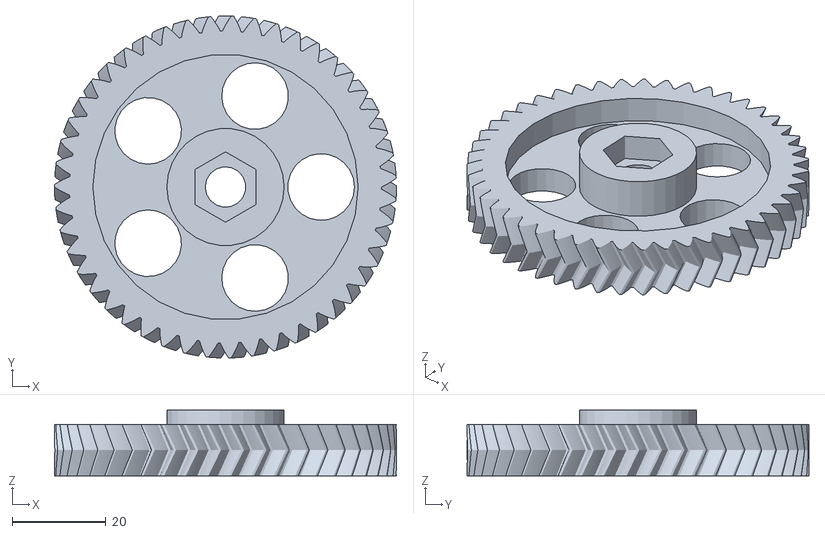
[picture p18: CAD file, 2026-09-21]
printed-parts/original-designs/upstream/jonaskuehling-18379/files/big-gear-mod_SAE.stl
73.0 x 73.0 x 14.0

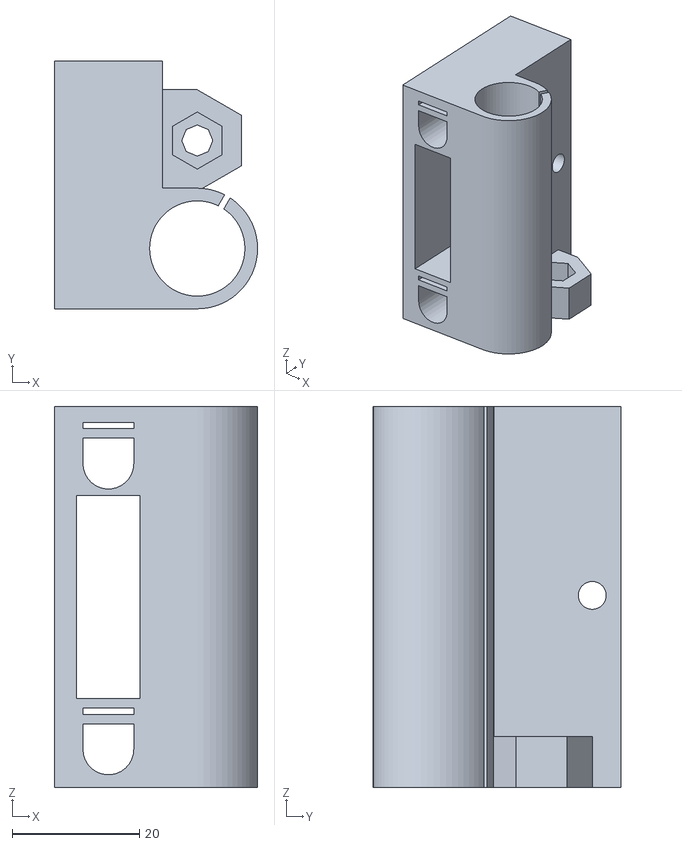
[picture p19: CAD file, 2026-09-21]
printed-parts/original-designs/upstream/clone-wars/Printers/Prusa3/Single_frame/x-end-idler.stl
32.0 x 39.0 x 60.0

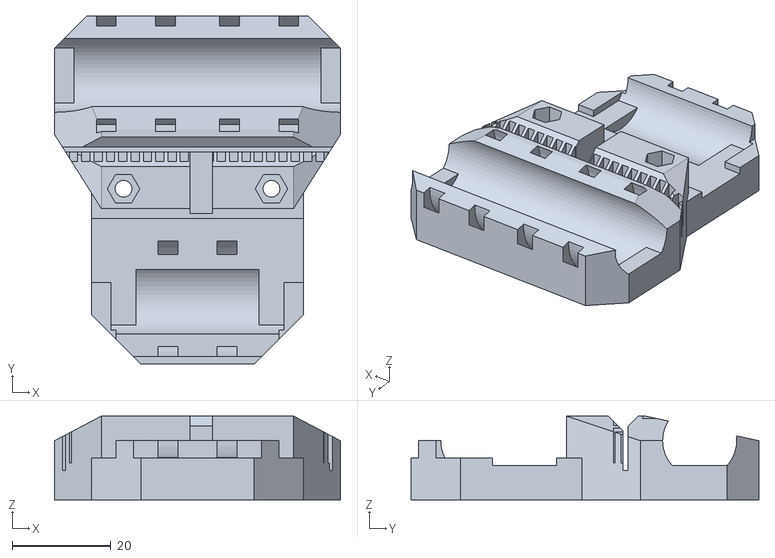
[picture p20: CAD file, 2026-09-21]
printed-parts/original-designs/upstream/clone-wars/Printers/Prusa3/Single_frame/x-carriage.stl
58.0 x 70.5 x 17.0

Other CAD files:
hardware/reference/bigtreetech/ebb36-gen2-v1.0/EBB36&42 GEN2 Adapter V1.0.step
hardware/reference/bigtreetech/manta-m8p-v2.0/BIGTREETECH MANTA M8P V2.0.step
printed-parts/original-designs/upstream/jonaskuehling-18379/files/jonaskuehling_gregs-wade-v3_reprapfaborg.stl
printed-parts/original-designs/upstream/jonaskuehling-18379/files/jonaskuehling_gregs-wade-v3_groovemount.stl
printed-parts/original-designs/upstream/jonaskuehling-18379/files/configuration.scad
printed-parts/original-designs/upstream/josefprusa-prusa3/box_frame/inc/settings.scad
printed-parts/original-designs/upstream/jonaskuehling-18379/files/functions.scad
printed-parts/original-designs/upstream/jonaskuehling-18379/files/gregs-wadebits.scad
printed-parts/original-designs/upstream/clone-wars/Printers/Prusa3/Single_frame/x-carriageV2.stl
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

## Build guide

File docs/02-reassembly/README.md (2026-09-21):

# Stage 02 — Original mechanical reassembly

Stage 02 reconstructs the printer from the documented original geometry before any modernization is applied.

The repository remains the source of truth. Reassembly decisions must distinguish between observed evidence, probable reconstruction and future improvements.

## Documentation

- `historical-manuals/` — period manuals that may be redistributed under their stated licenses.
- `historical-references.md` — period web references, provenance, relevance and licensing notes.
- `original-reassembly-manual.md` — project-specific assembly manual reconstructed from Stage 00/01 evidence and period documentation.
- [`../../photos/03-reassembly/`](../../photos/03-reassembly/) — Stage 02 photographic evidence archive.
- [`../../photos/03-reassembly/INDEX.md`](../../photos/03-reassembly/INDEX.md) — current reassembly photo inventory and evidence-group index.

The Stage 02 photo archive currently contains **116 privacy-sanitized JPEGs** in four batches: `RA-20260914-001` through `RA-20260914-035`, `RA-20260915-001` through `RA-20260915-009`, `RA-20260916-001` through `RA-20260916-058`, and `RA-20260921-001` through `RA-20260921-014`. The 14–15 September batches document Stage A structural reconstruction, component-shape references and the original steel frame mounted on the rebuilt Y base.

The 15 September batch records the Stage A checkpoint. The [16 September batch](../../photos/03-reassembly/BATCH-20260916.md) adds 58 photographs classified across manual Stages B–G. The [21 September batch](../../photos/03-reassembly/BATCH-20260921.md) adds 14 Stage H photographs of the geared-extruder subassembly. Assembly is reported complete in that batch; mounting and acceptance evidence remain to be recorded. These record reconstruction progress, not automatic completion of the manual operations or final mechanical acceptance checks.

## Temporary replacement parts during reassembly

Stage 02 should reuse original parts wherever they remain mechanically suitable, but broken or unusable printed parts may be reproduced when they block reconstruction.

Historical replacement candidates are now available in the [original printed-parts catalogue](../../printed-parts/original-designs/Original-Printed-Parts.md), including the [small Wade extruder gear](../../printed-parts/original-designs/Small-Extruder-Gear.md). Check the catalogue's identification status and physical interfaces before printing; an archived model is not a confirmed fit or completed reassembly step.

- Temporary/replacement printed parts should preserve the printer's historical **red-and-black** palette where practical.
- The colour of a replacement should preferably follow the original part if that can be established from the photographic record.
- **ABS is acceptable for Stage 02 replacement prints** when ASA is unavailable.
- These Stage 02 reproductions do not freeze the final material choice and should not be treated as modernization of the original geometry.
- For the final Generation 3 build, the project-wide visual policy is defined in `docs/final-build-architecture.md`: mechanical/structural printed parts are red, while frame and rods are black.

## Safety boundary

Stage 02 is mechanical. No mains-powered hardware is to be energized during this stage. Electronics may be positioned mechanically for historical reconstruction, but the old mixed wiring harness will not be reused.

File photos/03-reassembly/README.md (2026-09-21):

# Stage 02 — Reassembly photo archive

This directory contains privacy-sanitized photographic evidence for **Stage 02 — Original mechanical reassembly** of Prusa i3 Revival 2026.

## Batches

- Imported batches: **4**
- Imported photographs: **116**
- Naming prefix: `RA` = Reassembly
- Available ID ranges:
  - `RA-20260914-001` through `RA-20260914-035`
  - `RA-20260915-001` through `RA-20260915-009`
  - `RA-20260916-001` through `RA-20260916-058`
  - `RA-20260921-001` through `RA-20260921-014`

## Repository path

Sanitized evidence images are stored in:

`photos/03-reassembly/derived/reassembly-evidence/`

## Naming convention

`RA-YYYYMMDD-NNN-stage-x-subsystem-description.jpg`

## Documentation

- `manifest.csv` — cumulative photo inventory, provenance, dimensions and SHA-256. Empty `source_pixel_sha256` cells in the 21 September batch mean the pre-encoding source hash is unavailable; all repository JPEG hashes are present.
- `INDEX.md` — archive summary grouped by reconstruction stage.
- `BATCH-20260914.md` — initial Stage A archive.
- `BATCH-20260915.md` — final Stage A additions.
- `BATCH-20260916.md` — Stage B–G reconstruction batch.
- `BATCH-20260916-classification.csv` — per-image stage classification for the B–G batch.
- [21 September batch](BATCH-20260921.md) — Stage H geared-extruder assembly, photo links and remaining checks.
- [Stage H classification](BATCH-20260921-classification.csv) — per-image descriptions for the latest batch.
- `derived/reassembly-evidence/SHA256SUMS.txt` — cumulative integrity hashes.

All repository JPEGs are privacy-sanitized evidence copies. Generated illustrations and manual renders are excluded.

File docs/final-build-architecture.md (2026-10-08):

# Final build architecture — Generation 3

> Frozen architectural baseline for the **Revival 2026 final build**. Agreed 13 September 2026. Implementation remains deferred until the original and transitional generations have been documented and tested.

## Scope and generation model

This document defines the target control, electrical, thermal, sensing, user-interface and internal-network architecture for the final machine.

The project generations are:

1. **Original Hardware Revival** — Arduino Mega 2560 + RAMPS-era electronics and the legacy 3 mm / 2.85 mm machine.
2. **Re-ARM transitional study** — Panucatt Re-ARM + RAMPS-era hardware as the period 32-bit intermediate generation.
3. **Revival 2026 final build** — Manta/CB2/Klipper, 24 V, CAN toolhead and modern sensing while preserving the classic i3 character.

`Stage` in `docs/ROADMAP.md` means restoration workflow stage. **Generation 3** here is the final machine configuration and is not Roadmap Stage 03.

## Non-negotiable constraints

- Preserve the original steel frame, classic i3 silhouette and machine envelope.
- Preserve the historical lower threaded-rod structure as functional final hardware: **2× M10×350 mm longitudinal rods and 4× M8×200 mm transverse rods**. Do not replace this base with a modern aluminium-extrusion chassis.
- Preserve the **original heated-bed footprint and travel envelope**; do not enlarge the printer to fit a modern standard bed.
- Preserve original bed mounting geometry unless a hidden equivalent adapter is required.
- Hide modern electronics/cable management where practical.
- Give the 5-inch touchscreen a deliberately retro industrial enclosure/theme.
- Give any integrated camera a deliberate **retro video-surveillance / CCTV visual language**, rather than exposing a modern bare camera board or generic webcam shell.
- Build all mains and low-voltage wiring from scratch; the recovered harness remains archival evidence.
- Safety-critical protection must not depend solely on Linux, Klipper or CAN.

## Visual identity and colour policy

The final machine preserves the historical **red-and-black** visual identity of the original build without requiring an exact colour match to the filament used thirteen years earlier.

- All newly manufactured **mechanical and structural printed parts are red**.
- The exact shade of red is **not constrained**; consistency of the red/black language matters more than matching a specific historical filament, manufacturer or colour code.
- The **steel frame, rods and other exposed structural metalwork are black** where the design/material permits.
- **ASA is the preferred final material** for red printed mechanical/structural parts where suitable and available. Material choice must still respect mechanical, thermal and dimensional requirements.
- Electronics enclosures, camera housings, touchscreen housings and other newly introduced non-historical assemblies are **not bound to the red-printed-parts rule**. Their colour and material remain open until their design stage and will be selected according to function, thermal behaviour, ventilation, manufacturability and overall aesthetics.
- New enclosures may deliberately introduce another colour or material if doing so improves the final industrial/retro design language without weakening the historical red-and-black identity of the printer itself.

This is a design identity rule, not a requirement to reproduce the exact appearance or material of every original printed part.

## Core controller stack

### Main controller

**BIGTREETECH Manta M8P V2.0 + CB2 + TMC2209** is the frozen Generation 3 controller family. The Manta M8P V2.0 and six BTT TMC2209 V1.3 plug-in modules have been purchased; CB2 remains the frozen final host but is intentionally deferred until a sensibly priced unit is available. Four Manta drivers are expected for X/Y/Z0/Z1, with the Roto driven by the TMC2209 integrated on the EBB36 Gen2.

Initial Manta driver allocation:

| Channel | Function |
|---|---|
| X | X motor |
| Y | Y motor |
| Z0 | left Z motor |
| Z1 | right Z motor |
| Remaining sockets | spare/future documented expansion |

The extruder motor is driven locally by the EBB36 Gen2 onboard TMC2209. Z0 and Z1 remain independent for probe-assisted gantry alignment.

### Host software

The **CB2** runs:

- Klipper host;
- Moonraker;
- Mainsail;
- KlipperScreen;
- Crowsnest;
- Klipper resonance-analysis tools.

A separate Raspberry Pi is not part of the target architecture.

### Bench-test host before CB2

The Manta M8P V2.0 may be bench-tested before the CB2 is purchased by using a temporary Linux PC or Raspberry Pi as the Klipper host over USB. This is explicitly a commissioning/learning aid and does not change CB2 as the frozen final host.

## Local display

Use a **BIGTREETECH HDMI5 5-inch capacitive touchscreen** running KlipperScreen.

Integration requirements:

- custom ASA enclosure attached cleanly to the original frame;
- period/industrial visual language rather than a tablet-like mount;
- subdued default colours and no permanent gaming/RGB aesthetic;
- no significant increase in the printer envelope.

Mainsail remains available remotely from desktop, tablet or phone.

### RASS local spool touchscreen

A second, **smaller touchscreen** is mounted beside the RASS/spool assembly. It is a dedicated spool HMI rather than a second full KlipperScreen desktop.

The preferred implementation is a self-rendering **serial HMI with a wired connection to the Linux host**, normally through USB-to-serial or equivalent. This avoids relying on a second CB2 graphical-display pipeline while the primary BIGTREETECH HDMI5 remains the main KlipperScreen display.

The local panel shows spool identity/material/colour, remaining material, RFID/tag state, RASS/feed status, relevant warnings and nozzle readiness. It provides touch **LOAD** and **UNLOAD** requests.

The local panel has no direct authority over the RASS motors. CB1 during bench development and CB2 in the final machine own the UI state and command policy. LOAD/UNLOAD controls are enabled only when the host determines that no print is active and the extrusion/RASS state is safe; every touch request is revalidated on the host immediately before the corresponding macro/action is executed.

## Separate PSU enclosure and protected DC distribution

The final 24 V system has a **dedicated PSU enclosure** distinct from the Manta electronics enclosure. A suitably rated 230 V IEC inlet, two-pole main isolation switch, safety-compliant mains compartment, protective earth and a covered, individually fused 24 V DC distribution feed seven proposed **XT60E panel outlets**: controller logic, motor-driver supply, bed heater power stage, EBB/toolhead power, CAN low-power electronics, accessories and a capped reserve.

The toolhead and Bed Node use four-contact **XT30(2+2)** CAN-plus-logic/power connectors (vertical PCB and mating inline cable types). Bed heater current remains in its own higher-current two-conductor branch, **never** through the CAN/Bed Node logic feed. The existing 150–200 W heated-bed design target and LRS-600-24 preferred PSU remain unchanged; the final source, connector drawings, fuse sizing, conductor selection and Manta power domain separation require engineering validation before any wiring is energized.

For canonical pinout, wiring, interface safety, design gates and outlet IDs see [Generation 3 power distribution](../hardware/generation-3-power-distribution.md).

## CAN bus

CAN is a permanent internal bus in Generation 3, used where it reduces moving wiring and improves modularity.

- Manta M8P V2.0 provides the primary CAN interface.
- **BIGTREETECH CEB V1.0** is the protected CAN distribution/breakout point and physical backbone in the electronics bay.
- **BIGTREETECH EBB36 Gen2** is the permanent toolhead CAN node.
- The custom **Revival Bed Node** is a permanent CAN node connected through the CEB; it also retains USB-C for first flash, recovery, bench diagnostics and optional alternate USB runtime operation.
- The custom **RASS CAN Node** is a permanent Klipper-compatible CAN node connected through the CEB for active spool/feed control and local RASS sensing. It may interface the physical RFID/NFC reader, but forwards only low-level reader observations; tag/vendor/material decoding runs on the Linux host (CB1 during bench work, CB2 in the final machine).
- Both Revival-designed CAN nodes — Bed Node and RASS Node — run **unmodified upstream Klipper MCU firmware**. Revival-specific semantics remain in normal configuration/macros or Linux-host software; private MCU firmware forks are not part of the production architecture.
- Both custom nodes must physically expose **every remaining electrically usable MCU pin** after baseline functions are assigned. Alternate SPI/I2C/UART/ADC/GPIO/PWM capabilities are documented per pin; BOOT/RESET/debug remain separately accessible; only pins with a documented hardware reason may remain unavailable.
- The finished bus must have exactly two 120-ohm terminations at its physical ends; jumper positions are to be recorded during commissioning.
- CAN uses a twisted differential pair and a documented shielding/ground strategy.

CAN does **not** carry bed-heater power, camera video, touchscreen video or mains control.

## EBB36 Gen2 toolhead node

The moving toolhead harness is reduced to 24 V, ground, CAN-H and CAN-L, plus any required shield/drain arrangement.

The frozen Generation 3 extrusion/probing direction is **BIGTREETECH EBB36 Gen2 + E3D Roto + Revo + BIGTREETECH Eddy Duo**, documented in [`../hardware/generation-3-extrusion-toolhead.md`](../hardware/generation-3-extrusion-toolhead.md). The machine is quality-first for PLA, with occasional ABS/ASA capability but no heated-chamber requirement.

The EBB36 Gen2 locally manages:

- extruder stepper motor/driver;
- hotend heater;
- hotend temperature sensor;
- hotend heatsink fan;
- part-cooling fan;
- third auxiliary fan/output if required;
- BIGTREETECH Eddy Duo probe/scanner interface;
- filament sensor interface if selected;
- toolhead work/status lighting;
- toolhead sensors.

## Revival Bed Node

The final Generation 3 bed uses a custom **Revival Bed Node**, documented in [`../hardware/generation-3-bed-node.md`](../hardware/generation-3-bed-node.md). The board is fixed in a printed enclosure on the rear cross-member of the historical lower frame; it is not carried by the moving bed.

The implementation is deliberately staged:

1. **Initial commissioning:** conventional separate wiring — bed thermistor to Manta, external MOSFET controlled from the main electronics, and a separate USB S2DW-class bed accelerometer.
2. **Final architecture:** CAN-connected custom bed MCU near the moving Y assembly, integrating bed thermistor acquisition, permanent bed accelerometer and local heater power-stage control. Normal runtime communication is through the CEB; USB-C remains available for first flash, recovery, bench diagnostics and optional alternate runtime operation.

The fixed/semi-fixed communication feed into the Bed Node is **CAN through the CEB**, plus the required local logic supply. USB-C is an additional service/fallback interface, not the normal production data path. Only the short Bed Node-to-bed harness is continuously flexed and carries heater power, thermistor and the remote moving IMU connection. Neither CAN nor USB carries heater power; the heater retains its dedicated fused 24 V high-current path.

The Bed Node is a normal secondary Klipper MCU. Beyond bed control, it is also the local acquisition hub for a moving-bed IMU, a chassis IMU on the fixed PCB and a remote frame-top IMU, plus RGB status lighting and electrical/thermal telemetry. Safety-critical bed protection remains independent of it: dedicated branch fuse and independent thermal fuse remain mandatory even after migration.

## Permanent accelerometers

Generation 3 uses **two permanently installed accelerometers** because X and Y are different moving masses on a bed-slinger.

### X / toolhead

Use the **LIS2DW associated with the EBB36 Gen2**. It remains permanently installed and is read through the toolhead MCU/CAN node.

### Y / bed

During initial commissioning, use a permanent/semi-permanent **BIGTREETECH S2DW V1.0 (RP2040 + LIS2DW)** or equivalent USB accelerometer rigidly mounted to the moving bed/Y-carriage assembly. In the final architecture, the Bed Node remains fixed and a tiny LIS2DW-class IMU daughterboard remains rigidly attached to the moving bed/carriage.

During the transitional S2DW stage, connection is **USB directly to the CB2**. In the final architecture the moving-bed IMU is only a tiny sensor daughterboard; the fixed Bed Node acquires it locally and communicates with Klipper over CAN through the CEB. No CAN MCU or USB electronics are added to the moving bed.

The bed sensor mount must be rigid, electrically isolated where required, clear of heater/insulation and replaceable without disturbing bed alignment. The final moving harness carries only the short remote-IMU connection and bed-local power/sensor wiring; it does not require the transitional S2DW USB cable.

Klipper configuration will expose separate toolhead/X and bed/Y accelerometers so resonance tests require no sensor relocation.

## Heated bed — original footprint, modern layered construction

The final bed keeps the **exact original heated-bed footprint and machine travel envelope**. The currently catalogued Y carriage is approximately 220 × 220 mm and the old removable mirrors are 200 × 200 mm, but final plate CAD must use measurements from the original heated-bed PCB itself. The rule is: **match the original bed; do not enlarge it**.

Final stack, top to bottom:

1. removable spring-steel build sheet;
2. PEI surface (smooth/textured sheets may be separate consumables);
3. high-temperature magnetic base;
4. precision aluminium plate matching the original bed footprint and mounting geometry;
5. custom 24 V silicone heater;
6. integrated bed temperature sensor;
7. independent thermal fuse physically coupled to the bed/heater assembly;
8. thin thermal insulation where clearance permits.

The bed system is fixed at **24 V**. Heater wattage is selected only after the original PCB is accurately measured; current target range is approximately **150–200 W**.

The Manta controls the bed but the high-current heater path uses a **dedicated external DC MOSFET/power stage**. The bed circuit gets its own fuse, suitable wiring/connectors and an independent thermal fuse effective even if Klipper, CB2, Manta MCU or MOSFET fails.

## Camera architecture

Camera integration is part of the Generation 3 concept. The primary camera selection is now frozen as the **Innomaker U30CAM-4K-S1**, using a Sony IMX415 STARVIS sensor and USB/UVC. The earlier CSI-first/model-open direction is obsolete for the main frame camera. Optical framing and clean mechanical integration remain to be validated on the rebuilt printer. See [`../hardware/generation-3-main-camera.md`](../hardware/generation-3-main-camera.md).

### Main frame camera

The baseline requirement is one **fixed camera mounted to the printer frame**, never to the moving bed or toolhead.

Frozen implementation:

- **Innomaker U30CAM-4K-S1 over USB/UVC** is the primary frame camera;
- it is intended to work first with the CB1 bench host and remain the same camera through the future CB2 or CM4 host migration;
- advertised headline modes are 3840 × 2160 at 30 fps and 1920 × 1080 at 60 fps; delivered-unit V4L2 modes and sustainable host performance must be bench-verified.

Requirements:

- fixed, stable view of the bed/nozzle work area;
- wide enough field of view to remain inside the original printer envelope where practical;
- integration with Crowsnest/Mainsail;
- suitable for live monitoring, project documentation and timelapse;
- custom ASA enclosure inspired by **late-1980s/1990s industrial CCTV/video-surveillance cameras**;
- no exposed modern camera PCB and no generic consumer-webcam appearance.

The sensor and interface are frozen. Final mount position, focus, framing and normal operating mode are selected after physical tests with the delivered U30CAM-4K-S1.

### Possible future upgrade — fixed nozzle camera

A second camera is explicitly documented as a **possible future upgrade**, not part of the frozen base build.

Concept:

- a very small camera fixed to the toolhead/nozzle assembly;
- optical axis arranged so the nozzle remains at a stable position in the image;
- intended especially for timelapses in which the nozzle appears fixed while the printed part/bed moves through the frame;
- same retro CCTV visual language, miniaturised for the toolhead rather than left as an exposed board.

The likely implementation is **USB/UVC**, which would require an additional moving USB connection to the toolhead. This is intentionally deferred because it affects moving-harness flexibility, bend life, strain relief, electromagnetic routing, toolhead mass and available USB topology.

The nozzle camera must not be allowed to compromise the primary 24 V + CAN toolhead harness. If later adopted, its USB routing will be designed and tested as a separate moving service, or replaced by another suitable camera transport if a cleaner solution exists at that time.

The nozzle camera is **not** carried over CAN.

## Lighting

### Frame work light

- 24 V diffused COB/LED strip integrated discreetly into the frame;
- neutral-to-warm white, approximately 3500–4000 K preferred;
- dimmed by a Manta-controlled MOSFET output;
- Klipper macros may set idle/heating/printing/completed brightness states.

### Toolhead work/status light

- driven from the EBB36 Gen2 lighting/RGB interface;
- white work light at the nozzle during printing;
- restrained status colours for heating/completed/error states;
- no permanent rainbow effects by default.

## Fan architecture

| Function | Controller | Requirement |
|---|---|---|
| Hotend heatsink fan | EBB36 Gen2 | 24 V, tachometer-capable preferred; RPM monitoring in Klipper |
| Part cooling | EBB36 Gen2 | 24 V PWM blower sized after duct/hotend design |
| Auxiliary toolhead fan | EBB36 Gen2 | reserved for second cooling/toolboard need |
| Electronics enclosure | Manta | one or more large, low-RPM, temperature-controlled fans |
| CB2 cooling | local/Manta | fitted only if thermal tests require it |

Electronics airflow must be designed through the enclosure rather than relying on several permanently fast small fans.

## Power architecture

Generation 3 is a **24 V DC machine**.

```text
230 V AC
   |
   +-- fused / switched / filtered mains entry
   +-- protective earth -> steel frame / required exposed conductive parts
   |
   v
24 V PSU
   |
   +-- fused branch -> Manta / CB2
   +-- fused branch -> external bed MOSFET -> silicone bed heater
   +-- fused branch -> EBB36 toolhead power/CAN harness
   +-- fused branch -> frame lighting / auxiliaries
```

The PSU family remains Mean Well 24 V. Exact continuous wattage is selected after final bed-heater and hotend power are frozen, with real operating margin rather than simply matching arithmetic peak load.

## Software responsibility split

```text
Slicer
  |
  v
Mainsail / Moonraker
  |
  v
Klipper host on CB2
  |
  +-- Manta M8P V2 MCU -> X / Y / Z0 / Z1 / bed / enclosure I/O
  +-- CAN -> CEB V1.0 CAN backbone/distribution
  |      +-- EBB36 Gen2 -> extruder / hotend / fans / LEDs / X accelerometer
  |      |      +-- CAN passthrough -> Eddy Duo (separate 5 V CAN MCU/node)
  |      +-- Revival Bed Node -> bed control / Y IMU / structural IMUs / telemetry
  |      |      +-- USB-C service/recovery/optional alternate runtime
  |      +-- RASS CAN Node -> feeder / spool assist / buffer / encoders / local feed sensing
  |             +-- RFID/NFC reader acquisition -> raw observations -> host decoder service
  +-- USB -> BTT S2DW -> transitional Y/bed accelerometer before Bed Node
  +-- CSI preferred or USB fallback -> fixed frame camera
  +-- future USB/other link -> optional nozzle camera
```

Final configuration, macros and calibration data must be versioned under `firmware/` rather than living only on printer storage.

## Revival Intelligence & Diagnostics

**Revival Intelligence & Diagnostics (RID)** is the Generation 3 supervisory-intelligence and diagnostic umbrella hosted primarily on the CB2. It provides a common framework for future pre-flight checks, maintenance history, condition monitoring, vision, anomaly capture, sensor fusion and diagnostic user experience.

The concept and subsystem boundary are documented in [`../hardware/generation-3-revival-intelligence-diagnostics.md`](../hardware/generation-3-revival-intelligence-diagnostics.md). The prioritised feature backlog remains in [`../hardware/generation-3-enhancement-candidates.md`](../hardware/generation-3-enhancement-candidates.md).

RID does **not** move deterministic motion/heater control away from Klipper/Manta/EBB36/Eddy and does not replace independent hardware safety. Individual RID features remain candidates until separately promoted.

The intended responsibility split is:

- CB2/RID: observation, correlation, history, vision, diagnostics, notifications and tested reversible high-level actions;
- Klipper/Manta/EBB36/Eddy: deterministic machine control and normal firmware protections;
- independent hardware: mains, over-current, protective-earth, thermal-fuse and emergency-energy-removal functions.

RID should be local-first and should reuse already-frozen data sources before new hardware is added.

## Safety boundaries

The following must remain effective independently of normal host communication:

- mains fuse/switching and protective earth;
- correctly rated wire/connectors and branch protection;
- heated-bed thermal fuse;
- physical strain relief on all moving harnesses;
- hardware over-current protection independent of CAN/Klipper.

Klipper heater checks, fan RPM monitoring, temperature limits and watchdog behaviour are additional protections, not substitutes for electrical protection.

## Frozen architectural decisions

- original flat steel frame, original M8/M10 threaded-rod base and original machine/bed envelope;
- commercial aluminium T-slot extrusion as the local X/Y MGN12 support structure, with exact 2020/2040-class sections deferred to measured CAD;
- Z MGN12 mounting hierarchy: direct to the steel frame when metrology permits, thin aluminium backing plate if required, and T-slot extrusion only when necessary;
- historical red-and-black machine identity: red printed mechanical/structural parts, black frame/rods, with no exact red shade requirement;
- 24 V final system;
- Manta M8P V2.0 + CB2 + TMC2209 controller architecture; Manta and 6× TMC2209 are already purchased, CB2 pending;
- Klipper + Moonraker + Mainsail + KlipperScreen + Crowsnest;
- HDMI5 5-inch touchscreen with retro enclosure/theme;
- dedicated small RASS/spool touchscreen for local material status and host-guarded filament LOAD/UNLOAD controls;
- CAN as the permanent internal Generation 3 communications backbone;
- CEB V1.0 CAN distribution/protection and backbone for toolhead, Bed Node and RASS CAN Node;
- EBB36 Gen2 toolhead node;
- E3D Roto + Revo direct-drive extrusion stack;
- BIGTREETECH Eddy Duo for fast/dense eddy-current bed-surface scanning as an independent 5 V CAN node downstream of the EBB36 Gen2 passthrough;
- permanent X/toolhead LIS2DW;
- staged Y/bed sensing: initial USB S2DW-class accelerometer, final custom Revival Bed Node over CAN through the CEB with USB-C retained for service/recovery and optional alternate runtime;
- Bed Node and RASS Node use unmodified upstream Klipper MCU firmware and expose every remaining electrically usable MCU pin after final pin allocation, with alternate peripheral capabilities documented;
- one fixed **Innomaker U30CAM-4K-S1 Sony IMX415 USB/UVC** frame camera as the frozen primary imaging device;
- retro CCTV/video-surveillance enclosure language for all cameras;
- 24 V dimmable frame light and toolhead work/status light;
- tachometer-monitored hotend cooling architecture;
- temperature-controlled electronics ventilation;
- layered original-footprint aluminium/silicone/magnetic/flexible-PEI bed;
- external bed MOSFET and independent thermal fuse;
- complete new wiring.

## Possible future upgrades

- fixed toolhead/nozzle camera for nozzle-centred timelapse, likely USB/UVC but intentionally not frozen;
- additional CAN nodes only where they solve a demonstrated wiring/sensing problem rather than merely because CAN is available.

## Component-level selections still open

These selections do not change the architecture and will be frozen after their mechanical interfaces are known:

- exact Roto/Revo SKU/revision, toolplate geometry and final cooling integration;
- exact Eddy Duo mount, offsets, connector pinout, physical CAN harness and calibration/thermal-compensation strategy;
- exact filament sensor;
- exact fan models and duct geometry;
- exact frame-light strip/diffuser;
- final aluminium bed thickness;
- final silicone-heater dimensions/wattage after measuring the original bed PCB;
- exact PSU wattage;
- connector families, wire gauges and harness routing;
- U30CAM-4K-S1 frame-camera mount position, framing/focus and validated normal runtime mode;
- optional nozzle-camera implementation, if the future upgrade is adopted.

## RID computation policy

RID remains a local-first supervisory subsystem, but **LLM inference is not required locally**.

The CB2 runs the deterministic/specialist RID stack: sensor acquisition, feature extraction, anomaly detection, lightweight ML/vision, history and sensor fusion.

Any LLM is optional and may run on:
- a local-network server; or
- a configured external provider.

The machine remains fully printable and diagnostically useful when no LLM provider is available.

A future higher-performance compute module is not required merely to host an LLM.

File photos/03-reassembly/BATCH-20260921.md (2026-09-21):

# Batch — 21 September 2026

**Stage:** 02 — Original mechanical reassembly  
**Reassembly phase:** H — Wade-style geared extruder and legacy 3 mm extrusion hardware  
**Photo prefix:** `RA`  
**Batch range:** `RA-20260921-001` through `RA-20260921-014`  
**Repository evidence count in this batch:** 14

This batch documents completion of **Stage H**, concentrating on the reconstructed Wade/Greg's-Wade-family geared extruder, NEMA17 motor, large driven gear, small motor gear, idler/tension hardware and the recovered 3 mm filament-drive geometry.

## Evidence scope and remaining checks

The batch submission reports Stage H assembly complete. The photographs document the geared-extruder subassembly with its motor, gear pair and idler/tension hardware. They do not record the full mounting and acceptance checks from [manual Stage H](../../docs/02-reassembly/original-reassembly-manual.md#11-stage-h--wade-style-geared-extruder-and-legacy-3-mm-hotend) or the [final Stage 02 gate](../../docs/02-reassembly/original-reassembly-manual.md#14-final-stage-02-mechanical-checks).

Still requiring a recorded result are the hotend/X-carriage/fan installation, manual gear free movement/backlash, and filament-path alignment. Electrical and heated-extrusion tests remain outside Stage 02. The photographs also do not identify which archived STL, if any, was used for a reprint; original-design fit status remains open.

## Photo navigation

The [classification CSV](BATCH-20260921-classification.csv) owns the per-image descriptions. The links below open the unchanged repository evidence files.

| Photo | View |
| --- | --- |
| [RA-20260921-001](derived/reassembly-evidence/RA-20260921-001-stage-h-wade-extruder-overview-with-large-and-small-gears-installed.jpg) | Wade extruder overview with large and small gears installed |
| [RA-20260921-002](derived/reassembly-evidence/RA-20260921-002-stage-h-wade-extruder-motor-side-overview.jpg) | Wade extruder motor-side overview |
| [RA-20260921-003](derived/reassembly-evidence/RA-20260921-003-stage-h-wade-extruder-idler-and-spring-tension-assembly-overview.jpg) | Wade extruder idler and spring-tension assembly overview |
| [RA-20260921-004](derived/reassembly-evidence/RA-20260921-004-stage-h-wade-extruder-motor-and-gear-train-oblique-view.jpg) | Wade extruder motor and gear train oblique view |
| [RA-20260921-005](derived/reassembly-evidence/RA-20260921-005-stage-h-wade-extruder-idler-spring-and-hobbed-bolt-area-close-up.jpg) | Wade extruder idler spring and hobbed-bolt area close-up |
| [RA-20260921-006](derived/reassembly-evidence/RA-20260921-006-stage-h-wade-extruder-small-gear-and-hobbed-bolt-bearing-detail.jpg) | Wade extruder small gear and hobbed-bolt bearing detail |
| [RA-20260921-007](derived/reassembly-evidence/RA-20260921-007-stage-h-wade-extruder-gear-mesh-close-up.jpg) | Wade extruder gear mesh close-up |
| [RA-20260921-008](derived/reassembly-evidence/RA-20260921-008-stage-h-wade-extruder-gear-train-and-idler-side-close-up.jpg) | Wade extruder gear train and idler-side close-up |
| [RA-20260921-009](derived/reassembly-evidence/RA-20260921-009-stage-h-wade-extruder-assembled-overview-with-motor-wiring-visible.jpg) | Wade extruder assembled overview with motor wiring visible |
| [RA-20260921-010](derived/reassembly-evidence/RA-20260921-010-stage-h-wade-extruder-assembled-front-side-overview.jpg) | Wade extruder assembled front-side overview |
| [RA-20260921-011](derived/reassembly-evidence/RA-20260921-011-stage-h-wade-extruder-large-gear-and-central-hobbed-bolt-detail.jpg) | Wade extruder large gear and central hobbed-bolt detail |
| [RA-20260921-012](derived/reassembly-evidence/RA-20260921-012-stage-h-wade-extruder-assembled-top-oblique-view.jpg) | Wade extruder assembled top oblique view |
| [RA-20260921-013](derived/reassembly-evidence/RA-20260921-013-stage-h-wade-extruder-large-gear-face-close-up.jpg) | Wade extruder large gear face close-up |
| [RA-20260921-014](derived/reassembly-evidence/RA-20260921-014-stage-h-wade-extruder-large-gear-and-hub-close-up.jpg) | Wade extruder large gear and hub close-up |

## Processing policy

Every repository JPEG in this batch was:

1. decoded from the uploaded source image;
2. orientation-normalized using EXIF orientation when present;
3. converted to RGB pixel data;
4. re-encoded as high-quality JPEG;
5. written without EXIF, GPS, XMP, ICC profile, device or camera metadata.

No crop, resize, generative edit, object removal or other visible-content modification was applied.

## Duplicate handling

Exact duplicate detection was performed against the existing Stage 02 archive and within this batch.

Exact duplicates omitted: **0**.

## Inventory reconciliation — 21 September 2026

The 14 files were present in the repository but absent from the cumulative [manifest](manifest.csv) and [integrity list](derived/reassembly-evidence/SHA256SUMS.txt). Their actual JPEG hashes and dimensions are now recorded, bringing the archive to 116 photographs in four batches. No image bytes were changed.

The original pre-encoding source-pixel hashes were not preserved in the available batch record. Their `source_pixel_sha256` cells are intentionally empty; a hash of the current JPEG pixels must not be substituted for a source-pixel hash. The original filenames and capture date follow the classification record and batch identity. The existing processing account above is retained; the review independently verified readable JPEGs with no EXIF/GPS/XMP/ICC fields exposed by the image reader and no byte-identical duplicates against the cumulative archive.

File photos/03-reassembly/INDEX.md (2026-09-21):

# Stage 02 photo index

## Archive summary

- Total photographs: **116**
- Batch 1: `RA-20260914-001` → `RA-20260914-035`
- Batch 2: `RA-20260915-001` → `RA-20260915-009`
- Batch 3: `RA-20260916-001` → `RA-20260916-058`
- Batch 4: `RA-20260921-001` → `RA-20260921-014`

## Existing Stage A groups

- `RA-20260914-001` → `RA-20260914-010` — early Y-axis support references.
- `RA-20260914-011` → `RA-20260914-025` — Stage A structural rebuild sequence.
- `RA-20260914-026` → `RA-20260914-035` — geometry and part-shape references.
- `RA-20260915-001` → `RA-20260915-009` — final Stage A additions.

## 16 September 2026 — Stages B through G

### Stage B — Y linear guides and bed carriage
- `RA-20260916-001` → `RA-20260916-022` (22 photographs)
### Stage C — Y motor, idler and T2.5 transmission
- `RA-20260916-023` → `RA-20260916-027` (5 photographs)
### Stage D — Heated bed, levelling springs and mirror
- `RA-20260916-028` → `RA-20260916-035` (8 photographs)
### Stage E — Z lower mounts, motors and smooth guides
- `RA-20260916-036` → `RA-20260916-044` (9 photographs)
### Stage F — X ends, X carriage and X guide rods
- `RA-20260916-045` → `RA-20260916-051` (7 photographs)
### Stage G — Join X gantry to Z
- `RA-20260916-052` → `RA-20260916-058` (7 photographs)

## 21 September 2026 — Stage H geared extruder

- `RA-20260921-001` → `RA-20260921-014` (14 photographs).
- [Batch and photo links](BATCH-20260921.md) · [classification](BATCH-20260921-classification.csv) · [Phase H](../../docs/knowledge-base/build/Phase-H.md).

Assembly is reported complete in the batch submission; the photographs document the geared-extruder subassembly. Stage H mounting/acceptance evidence and the final Stage 02 checks remain to be recorded. No dedicated Stage I or J batch is currently indexed.

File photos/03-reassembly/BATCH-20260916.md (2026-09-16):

# Batch — 16 September 2026

**Stage:** 02 — Original mechanical reassembly  
**Photo prefix:** `RA`  
**Batch range:** `RA-20260916-001` through `RA-20260916-058`  
**Repository evidence count in this batch:** 58

This batch documents physical reconstruction progress from **Stage B through Stage G**.

## Classification

- **Stage B — Y linear guides and bed carriage:** 22 photographs.
- **Stage C — Y motor, idler and T2.5 transmission:** 5 photographs.
- **Stage D — Heated bed, levelling springs and mirror:** 8 photographs.
- **Stage E — Z lower mounts, motors and smooth guides:** 9 photographs.
- **Stage F — X ends, X carriage and X guide rods:** 7 photographs.
- **Stage G — Join X gantry to Z:** 7 photographs.

The detailed per-image assignment is recorded in `BATCH-20260916-classification.csv`.

## Processing policy

Every repository JPEG in this batch was:

1. decoded from the uploaded source image;
2. orientation-normalized using EXIF orientation when present;
3. converted to RGB pixel data;
4. re-encoded as high-quality JPEG;
5. written without EXIF, GPS, XMP, ICC profile, device or camera metadata.

No crop, resize, generative edit, object removal or other visible-content modification was applied.

## Duplicate handling

Exact duplicate detection was performed on orientation-normalized RGB pixel data, both against the existing Stage 02 archive and within this batch.

Exact duplicates omitted: **0**.

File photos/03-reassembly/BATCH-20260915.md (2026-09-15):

# Batch — 15 September 2026

**Stage:** 02 — Original mechanical reassembly  
**Photo prefix:** `RA`  
**Repository evidence count in this batch:** 9

This batch adds the last Stage A reassembly photographs before progressing to the next reconstruction phase.

## Processing policy

The repository receives privacy-sanitized evidence copies rather than phone/camera originals. Sanitization removes embedded metadata while preserving the visible image content and original pixel dimensions.

## Content groups

- Y-frame after rectangular base completion.
- Front Y idler support with pulley installed.
- Main steel frame mounted on the Y base.
- Rear Y motor support with stepper installed.
- Close references for fastener orientation and support geometry.

## Exclusions

The following are intentionally excluded:

- AI-generated assembly illustrations;
- manual page renders;
- infographics;
- SVG/PDF/DOCX manual assets.

## Duplicate handling

Exact duplicate detection was performed on orientation-normalized RGB pixel data before export.

Exact duplicates omitted from this package: **0**.

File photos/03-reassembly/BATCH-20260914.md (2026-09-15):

# Batch — 14 September 2026

**Stage:** 02 — Original mechanical reassembly  
**Photo prefix:** `RA`  
**Repository evidence count:** 35

This batch consolidates all real reconstruction photographs uploaded in the working chat through the end of the Stage A frame discussion.

## Processing policy

The repository receives privacy-sanitized evidence copies rather than phone/camera originals. Sanitization removes embedded metadata while preserving the visible image content and original pixel dimensions.

## Content groups

- Component and hardware references for Stage A.
- Original front Y idler support from multiple angles.
- Front and rear Y crossmember assembly.
- M10 side rods and steel-frame clamping hardware.
- Completed rectangular Y base.
- Original steel frame positioned and mounted.

## Exclusions

The following are intentionally excluded:

- AI-generated assembly illustrations;
- manual page renders;
- infographics;
- SVG/PDF/DOCX manual assets.

## Duplicate handling

Exact duplicate detection was performed on orientation-normalized RGB pixel data before export.

Exact duplicates omitted from this package: **0**.

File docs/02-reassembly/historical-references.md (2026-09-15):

# Historical references — Stage 02 reassembly

This index records period sources used to reconstruct how a Prusa i3 of this family would have been assembled around 2012–2014. The project manual does not assume that any generic i3 source exactly matches this printer; repository photographs and measured inventory remain authoritative when they disagree.

## Reference policy

- **Observed project evidence wins** over generic historical instructions.
- Period sources are used to reconstruct assembly logic, naming, orientation and contemporary practice.
- Exact dimensions from external sources are not copied into the build unless confirmed against this printer.
- Documents are stored locally only when redistribution terms are sufficiently clear; otherwise only the external reference is recorded.

## Core sources

### SpainLabs — "Manual de montaje Prusa i3" (3 August 2013)

- URL: https://www.spainlabs.com/foros/showthread.php?tid=228
- Date: 2013-08-03
- Language: Spanish
- Local copy: **not stored**; no explicit redistribution license was identified.
- Importance: **very high** for this specific machine family.
- Why it matters: its published BOM lists 2× M5×310 mm, 4× M8×200 mm, 2× M10×350 mm, 10× LM8UU and 3× 608ZZ — an unusually close match to the recovered printer. The thread also discusses 2.5 A / 1.8° motors and 5-to-5 mm Z couplers, again matching the recovered hardware family.
- Caution: the thread mixes variants and contains known inconsistencies/typos; dimensions and transmission type must be checked against project evidence.

### RepRap Magazine Issue 2 — "Prusa i3 visual instructions" (June 2013)

- Archive page: https://xyzdims.com/3d-printing/reprap-magazine-archive/
- PDF: https://xyzdims.com/wp-content/uploads/2018/07/reprap-magazine-21.pdf
- Original date: 2013-06
- License reported by archive: Creative Commons CC BY-NC-ND.
- Local copy: stored unchanged in `historical-manuals/` when available.
- Importance: high as a contemporary visual assembly source; SpainLabs explicitly states that its August 2013 guide began as a translation/adaptation of this article.
- Caution: the magazine article covers a specific single-plate/Einstein-style configuration and is not dimensionally identical to the recovered printer.

### RepRap / Clone Wars — Prusa iteration 3

- URL: https://reprap.org/wiki/Clone_wars:Prusa_iteración_3
- Period context: Spanish Clone Wars community documentation from the original Prusa i3 era.
- Importance: high for historical context and contemporary Spanish build practice.
- Notable content: links to step-by-step frame, X, Y, Z, heated-bed, extruder and electronics instructions; references the Josef Prusa repository and contemporary video tutorials.
- Local copy: not stored as a webpage snapshot; linked here instead.

### RepRap Wiki — Prusa i3 Build Manual

- URL: https://wiki.reprap.org/wiki/Prusa_i3_Build_Manual
- Importance: high for canonical i3 dimensions, variants and links to original Josef Prusa source files.
- Local copy: not stored as a webpage snapshot; linked here instead.
- Caution: the page covers multiple variants and its generic dimensions do not fully match this printer.

### Josef Prusa — Prusa3 repository

- URL: https://github.com/josefprusa/Prusa3
- License: GPLv3.
- Importance: primary upstream design source for the era.
- Files of interest: historical build notes/manual, dimensions and CAD/reference assemblies.
- Local copies: selected text documentation may be stored in `historical-manuals/` with upstream attribution and license notice.

### RepRap Wiki — Prusa Mendel Assembly (iteration 2)

- URL: https://wiki.reprap.org/wiki/Prusa_Mendel_Assembly_(iteration_2)
- Importance: useful for period assembly conventions inherited by the i3, especially Wade-style geared extruder mounting, belt tension and free-motion checks.
- Local copy: not stored; referenced by URL.

### RepRap Wiki — Prusa i3 Rework Extruder assembly

- URL: https://wiki.reprap.org/wiki/Prusa_i3_Rework_Extruder_assembly
- Importance: useful secondary period-family reference for Wade extruder body, idler, 608 bearings, springs and carriage connection.
- Local copy: not stored; referenced by URL.

### Clone Wars / RepRap — "MONTAJE PRUSA i3 MARCO DE MADERA"

- PDF: https://reprap.org/mediawiki/images/4/46/Prusai3boxframeconstruction.pdf
- Attribution in document: translation/adaptation by Juampe López and Ariadna Trueba from Kliment's i3 photographic documentation.
- License stated in document: GFDL.
- Importance: secondary source for period assembly technique, Y-frame alignment, Z assembly, heated bed, endstops and Jonas extruder.
- Local copy: stored unchanged in `historical-manuals/` when available.
- Caution: this is a box-frame build and dimensions differ significantly from the recovered single-sheet machine.

## Video-era references

The period RepRap/Clone Wars pages also point to:

- "Montando la Prusa Mendel i3" (Spanish): https://www.youtube.com/watch?v=-31Zn7wY7jk
- OverCraft3D aluminium-body Prusa i3 assembly series, linked from the contemporary Clone Wars/RepRap pages.

These are retained as contextual references; the project manual relies on still photographs and measured evidence for any orientation or dimension that must be reproduced exactly.

## Project evidence to consult alongside historical sources

Primary visual evidence is in:

- `photos/00-archaeology/`
- `photos/02-teardown/originals/`
- `photos/02-teardown/derived/component-inventory/`

Especially relevant early references include `TD-20260913-003` through `012` for Z geometry, `TD-20260913-005`, `021`, `032`, `038` for the Y structure and drive, `TD-20260913-023` through `030` for X/extruder geometry, `TD-20260913-039` and `040` for the installed hotend, and `TD-20260913-160` through `228` for cleaned component identification and measurements.

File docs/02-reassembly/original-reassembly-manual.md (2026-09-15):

# Original Prusa i3 Reassembly Manual — Revival 2026

> Historical reconstruction guide for Stage 02. This manual intentionally approaches the printer as it would have been assembled in the 2012–2014 RepRap era, while using the recovered printer itself as the final authority.

## 1. Purpose and evidence hierarchy

This manual reconstructs the original mechanical Prusa i3 before modernization. It is not a generic modern i3 guide.

Evidence priority:

1. Stage 00/01 photographs and measured recovered components.
2. Teardown sequence and component-inventory records.
3. Contemporary 2012–2014 assembly sources.
4. Later derivative documentation only where it explains an unchanged mechanical principle.

Every instruction is tagged conceptually as one of:

- **Observed** — visible or measured on this printer.
- **Probable** — strongly supported by period documentation and the recovered parts, but still to be verified during assembly.
- **Future improvement** — recorded for later stages and not applied here.

## 2. Historical fit of this machine

The recovered hardware aligns unusually closely with the Spanish community Prusa i3 build documented by SpainLabs on 3 August 2013. That guide lists 2× M5×310 mm Z threaded rods, 4× M8×200 mm Y cross rods, 2× M10×350 mm Y longitudinal rods, 10× LM8UU and 3× 608ZZ bearings. The same discussion references 2.5 A / 1.8° motors and 5-to-5 mm Z couplers. Those values closely match this printer's recovered hardware.

This makes the SpainLabs guide a strong historical clue, but not an authority over the physical evidence. The recovered smooth-rod lengths, belt type, printed parts and exact frame geometry differ from several published variants.

## 3. Tools and preparation

Prepare a clear bench and keep the Stage 01 photographs accessible.

Recommended hand tools:

- metric hex keys;
- 5.5 mm, 8 mm, 13 mm and 17 mm spanners/nut drivers as required by the recovered fasteners;
- small adjustable spanner;
- screwdrivers;
- vernier caliper;
- steel ruler;
- engineer's square;
- marker and removable labels;
- side cutters for temporary cable ties;
- lint-free cloths and suitable cleaning supplies;
- appropriate lubricant for the linear guides, applied only after bearing condition is assessed.

Do not connect the PSU to mains power during Stage 02.

## 4. Stage A — Y-frame structural base and steel frame

### Parts to prepare

- 2× M10×350 mm threaded rods;
- 4× M8×200 mm threaded rods;
- four original Y-corner printed parts;
- original Y motor support and Y idler support;
- M8/M10 nuts and washers from the recovered fastener set;
- single-sheet steel vertical frame.

### Historical reconstruction logic

**Observed:** the recovered inventory contains the same M10×350 and M8×200 threaded-rod pattern as the 2013 SpainLabs guide. `TD-20260913-005` and `TD-20260913-021` record the assembled lower structure before teardown.

**Probable:** the base should first be assembled as two M8 cross-members — one carrying the Y idler and one carrying the Y motor support — and then joined by the two M10 longitudinal rods. This is the sequence used in the contemporary SpainLabs instructions and is mechanically consistent with the recovered parts.

### Assembly

1. Lay out the four M8×200 rods in two pairs. Do not tighten anything fully yet.
2. Identify the original front/idler support by comparison with `TD-005`, `TD-021` and `TD-038`.
3. Fit the idler support approximately at the centre of its M8 pair, using a washer and nut on each side of the printed part where the original geometry shows this arrangement.
4. Fit two Y-corner pieces to the ends of that M8 pair.
5. Repeat with the rear pair using the Y motor support and the remaining two Y corners.
6. Pass the two M10×350 rods through the four Y corners to connect the front and rear assemblies.
7. Before closing the M10 ends, install the inner washers/nuts that will later clamp the steel frame. Contemporary 2013 instructions explicitly placed these near the middle before final assembly because they cannot be added later without dismantling the base.
8. Place the steel frame between the inner washer/nut pairs, matching the orientation visible in the teardown photographs. Do not yet assume equal distances from the rod ends; reproduce the photographed geometry.
9. Square the Y rectangle. Measure both diagonals and adjust until they are equal within practical measurement error.
10. Confirm that the two M10 rods are parallel and that the M8 front/rear cross-members are perpendicular to them.
11. Only then progressively tighten the structural nuts, alternating sides so the plastic corners are not twisted.

### Stop-and-check gate

Before continuing, photograph the complete base from above and from both sides. The steel frame must stand perpendicular to the Y base without visible twist.

**Future improvement:** none applied. Later stages may replace fatigued printed corners or change structural hardware, but Stage 02 preserves the original architecture.

## 5. Stage B — Y linear guides and bed carriage

### Parts to prepare

- recovered Y smooth-rod pair — currently catalogued as the probable Ø8×350 mm pair;
- Y carriage plate (~220×220 mm, ~210 mm mounting-hole spacing, ~6 mm thick);
- 3× LM8UU for Y;
- original LM8UU retention method/hardware;
- Y belt holder.

### Assembly

1. Use the pre-teardown photographs to determine which side of the Y carriage faced upward.
2. Install three LM8UU bearings in the same 1+2 arrangement visible in the original build. Do not substitute a four-bearing layout.
3. If the original carriage used cable ties through slots to hold the LM8UU bearings, reproduce that only for the historical reconstruction; use new ties rather than brittle old ones.
4. Install the Y belt holder in its original position and orientation.
5. Clean the two probable Y rods and inspect for scoring, corrosion or bends before inserting them.
6. Slide the rods through the LM8UU bearings gently. Never hammer a rod through a bearing.
7. Seat the smooth rods into the Y-corner grooves/retainers as shown by the original geometry.
8. Move the carriage by hand through the entire travel. It must move freely without forcing either rod inward or outward.
9. If motion binds, loosen the Y-frame nuts and align the frame around the carriage rather than forcing the bearings to compensate for a skewed base.

### Bearing classification

Classify each LM8UU as **REUSE**, **RESTORE** or **REPLACE** according to noise, roughness, play and visible damage. Do not lubricate a visibly damaged bearing as a substitute for replacement.

## 6. Stage C — Y motor, idler and T2.5 transmission

### Parts to prepare

- 1× Wantai 42BYGHW811 motor;
- original Y motor bracket already installed in the base;
- T2.5 ~20-tooth drive pulley;
- original Y idler hardware;
- appropriate FAG 608Z bearing if confirmed by photographs for this location;
- T2.5 belt.

### Assembly

1. Compare motor orientation with `TD-021`, `TD-032` and `TD-038` before installing it.
2. Mount the motor loosely enough to permit pulley alignment.
3. Fit the T2.5 pulley with its teeth in the same belt plane as the carriage belt holder.
4. Reconstruct the front idler from the photographs. Do not substitute the 623ZZ arrangement shown in some contemporary manuals if the recovered machine used a 608Z.
5. Route the T2.5 belt around the motor pulley and idler, with the toothed face engaged on the drive pulley.
6. Attach both belt ends to the original Y belt holder.
7. Align the belt so its long runs are parallel to the Y rods and approximately horizontal.
8. Tension only enough to remove slack. Period instructions consistently warn against an over-tight belt; the carriage must remain smooth over full travel.

**Observed:** the recovered belt and pulley are T2.5, not GT2. Period sources that show GT2 are useful for routing logic only.

## 7. Stage D — Heated bed, levelling springs and mirror

### Parts to prepare

- original heated-bed PCB;
- four original long M3 bed screws;
- original levelling springs, including the repurposed clothes-peg springs;
- washers/nuts as documented;
- one IKEA SÖRLI 200×200×3 mm mirror;
- original mirror clips if recovered and serviceable.

### Assembly

1. Confirm which face of the Y carriage is uppermost from the teardown photos.
2. Insert the four levelling screws through the carriage/bed mounting points in the original direction.
3. Recreate the original spring stack at all four corners. Do not replace the springs yet; their unusual origin is part of the documented machine history.
4. Install the heated bed mechanically but do not connect its wiring.
5. Compress the springs only enough to make the bed stable while leaving useful adjustment travel in both directions.
6. Place the SÖRLI mirror on the bed and secure it using the original clip arrangement if that arrangement can be proven from photographs.
7. Check that no clip can collide with the nozzle path at the future print limits.

**Future improvement:** purpose-made bed springs/spacers and a modern build surface may be evaluated after the original baseline is reconstructed.

## 8. Stage E — Z lower mounts, motors and smooth guides

### Parts to prepare

- 2× Wantai 42BYGHW811 motors;
- original lower Z motor mounts;
- probable Z smooth rods — catalogued Ø8×330 mm;
- Z top supports;
- 4× LM8UU assigned to the X-end assemblies;
- 2× flexible aluminium Z couplers;
- 2× M5×310 mm threaded rods.

### Assembly

1. Identify left/right Z mounts using `TD-003` through `TD-012` and `TD-030` where relevant.
2. Mount both lower Z motor brackets to the steel frame in their original holes and orientation.
3. Install the two Z motors but leave final motor/bracket tightening until rod alignment is checked.
4. Install the two smooth Z rods in the lower mounts.
5. Fit the upper Z supports while ensuring each smooth rod remains straight and unstressed.
6. The smooth rods must be parallel to one another and approximately perpendicular to the Y plane.
7. Do not install the M5 threaded drive rods permanently until the X gantry ends have been prepared.

## 9. Stage F — X ends, X carriage and X guide rods

### Parts to prepare

- X-end motor printed part;
- X-end idler printed part;
- remaining LM8UU bearings for the X ends;
- X carriage with its 3× LM8UU bearings;
- recovered probable X smooth-rod pair — catalogued Ø8×317 mm;
- X motor;
- T2.5 pulley;
- X idler bearing/hardware;
- X belt.

### Assembly

1. Reconstruct the X-end idler using the bearing and fastener arrangement visible in the teardown photos.
2. Insert the LM8UU bearings into the two X ends in the same orientation used originally.
3. Install the M5 drive nuts in the X ends if the original parts use trapped M5 nuts. Period i3 instructions placed these nuts before the X/Z marriage because access becomes difficult later.
4. Install 3× LM8UU into the X carriage using the original retention method.
5. Pass the two X smooth rods through the carriage bearings.
6. Fit the X-end motor and X-end idler to the rod ends. Use `TD-027`, `TD-028` and `TD-030` to establish which side contains the motor.
7. Move the X carriage by hand through the complete span before tightening anything that could distort the rod spacing.
8. Mount the X motor and T2.5 pulley.
9. Route the X belt around the motor pulley and idler and secure it to the X carriage in the original fashion.
10. Tension only enough to remove backlash without increasing carriage drag.

## 10. Stage G — Join X gantry to Z

1. With both Z smooth rods installed, slide the X-end LM8UU bearings onto the Z rods simultaneously.
2. Lower both sides evenly; never force one side far ahead of the other.
3. Insert the two M5×310 threaded rods through the trapped M5 nuts in the X ends.
4. Connect each M5 rod to its Z motor using the recovered flexible aluminium coupling.
5. Before tightening coupler screws, align each threaded rod as closely as possible with its motor shaft and the associated Z smooth rod.
6. Turn both M5 rods by hand together and raise/lower the X gantry. It should move without periodic binding.
7. Level the X gantry relative to the Y carriage by turning the two Z screws independently by hand.

**Observed:** this printer uses aluminium flexible couplers. Some 2013 guides used short rubber hose; that is historical context only and is not reproduced here.

**Future improvement:** Stage 03 will replace the M5 threaded rods with proper leadscrews only after the original geometry is validated.

## 11. Stage H — Wade-style geared extruder and legacy 3 mm hotend

### Parts to prepare

- Wade/Greg's-Wade-family extruder body;
- large printed gear;
- small motor gear;
- hobbed bolt and associated washers/nut/bearings;
- idler assembly, tension screws and springs;
- extruder NEMA17 motor;
- legacy E3D-family groove-mount hotend;
- hotend fan/supports as originally fitted;
- thermistor and captive heater cartridge retained for documentation.

### Historical assembly logic

Period Prusa Mendel instructions recommended assembling the hotend to the Wade body and mounting the body to the carriage before finally fitting the motor, large gear/hobbed bolt and idler. This avoids losing access to mounting screws.

### Assembly

1. Compare the complete extruder against `TD-002`, `TD-023` through `TD-025`, `TD-039` and `TD-040` before separating subcomponents further.
2. Build the hobbed-bolt/large-gear stack using the same washer and bearing order visible in the teardown evidence.
3. Install the idler bearing and hinge/tension hardware.
4. Do not fully compress the idler springs yet.
5. Mount the E3D-family hotend in the original groove-mount position beneath the extruder body.
6. The heater cartridge remains captive in the heater block because its retaining screw head is damaged. Do not attempt destructive removal during Stage 02.
7. Mount the extruder body to the X carriage in the original orientation.
8. Mount the extruder motor and small gear.
9. Mesh the small and large gears with a small amount of backlash; they must not bind.
10. Align the hobbed section of the drive bolt with the 3 mm filament path.
11. Tighten the idler springs evenly until the idler can grip filament, but leave final extrusion pressure to commissioning.
12. Refit the heatsink fan/support arrangement as documented.

No heater or thermistor wiring is energized in Stage 02.

## 12. Stage I — Endstops

### Parts to prepare

- original mechanical X, Y and Z endstop modules;
- their original printed mounts/fasteners.

### Assembly

1. Use `TD-009`, `TD-035` and the teardown endstop series around `TD-147…154` to identify each switch and mount.
2. Install X, Y and Z switches mechanically in their photographed positions.
3. Move each axis slowly by hand and confirm that the switch is physically actuated before any hard collision occurs.
4. Do not infer electrical NO/NC wiring from physical orientation; electrical validation belongs to a later stage.

## 13. Stage J — Electronics placement, historical only

### Parts to prepare

- Arduino Mega 2560;
- StaticBoards RAMPS 1.4SB;
- four A4988-family drivers;
- LCD and RAMPS adapter;
- original controller cooling fans/supports;
- JCPOWER JC-360-12 PSU only for mechanical positioning.

### Assembly

1. Use `TD-013` through `TD-020`, `TD-026`, `TD-029`, `TD-031` and the cleaned inventory photographs to reproduce component locations.
2. Use insulating spacers where the original electronics were mounted to the metal frame.
3. Position the PSU mechanically only if useful for reconstructing the original machine layout.
4. Keep all mains terminals disconnected and protected from accidental contact.
5. The original mixed wiring harness is reference evidence only and is **not reused**.

## 14. Final Stage 02 mechanical checks

Do not proceed to electrical work until all checks pass:

- Y-frame diagonals agree and the steel frame is square to the base;
- Y carriage travels end-to-end with no tight spot;
- X carriage travels end-to-end with no tight spot;
- X gantry rises and falls by turning both Z screws manually;
- X and Y belts stay in their pulley/idler planes;
- pulleys are secure on motor shafts;
- no LM8UU is forced sideways by misaligned rods;
- heated bed is stable and has useful levelling travel;
- each endstop is reached before a mechanical crash;
- extruder gears turn freely by hand;
- hotend is mechanically secure;
- loose wiring cannot enter belts, gears or fans.

At this point the printer should look and move like the historical machine, but it is still an unpowered mechanical reconstruction.

## 15. Component condition log

For every component touched during Stage 02 record one primary state:

- **REUSE** — acceptable after inspection;
- **RESTORE** — requires cleaning, lubrication or repair before reuse;
- **REPLACE** — equivalent replacement required for the original baseline;
- **REDESIGN** — intentionally deferred to a modernization stage;
- **ARCHIVE** — retained mainly as historical evidence.

Use notes to distinguish cleaning, lubrication and repair work without expanding the repository's primary status vocabulary.

## 16. Historical references

See `historical-references.md` for the complete source index and licensing notes. The most influential sources for this reconstruction are:

- SpainLabs, **Manual de montaje Prusa i3**, 3 August 2013;
- RepRap Magazine Issue 2, **Prusa i3 visual instructions**, June 2013;
- RepRap / Clone Wars, **Prusa iteration 3** documentation;
- Josef Prusa, **Prusa3** GPLv3 repository;
- RepRap Wiki, **Prusa Mendel Assembly (iteration 2)** for Wade-extruder practice;
- RepRap / Clone Wars, **MONTAJE PRUSA i3 MARCO DE MADERA** as a secondary period mechanical reference.

The sources explain contemporary assembly practice; the recovered printer determines the final answer whenever variants conflict.

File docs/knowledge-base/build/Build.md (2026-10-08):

---
type: index
area: build
status: in-progress
phase: stage-02
priority: high
updated: 2026-10-08
---

# Build

The [canonical roadmap](../../ROADMAP.md) defines restoration stages 00–10. The [original reassembly manual](../../02-reassembly/original-reassembly-manual.md) uses lettered Stages A–J inside Stage 02. Those letters are not additional roadmap stages.

| Roadmap stage | Canonical scope | Recorded status |
|---|---|---|
| 00 | Archaeology | Complete, 12 September 2026 |
| 01 | Teardown, cleaning and inventory | Complete, 13 September 2026 |
| 02 | Original mechanical reassembly | In progress |
| 03 | Revival Z axis | Planned |
| 04 | Printed parts | Planned |
| 05 | Electronics, power and new wiring | Planned |
| 06 | Legacy 3 mm / 2.85 mm extrusion | Planned |
| 07 | Firmware and commissioning | Planned |
| 08 | Legacy Filament Lab | Planned |
| 09 | 1.75 mm conversion | Planned |
| 10 | Results | Planned |

The roadmap also defines a continuous bilingual blog workstream. It is not another build phase.

## Current work

Start with [Stage 02: original reassembly](Stage-02-Original-Reassembly.md). Follow the source manual for procedures and record condition decisions against the existing hardware inventory rather than creating a second inventory here.

The [photo index](../../../photos/03-reassembly/INDEX.md) now records evidence through manual Stage H. The [latest batch](../../../photos/03-reassembly/BATCH-20260921.md) reports geared-extruder assembly complete, with remaining mounting/acceptance evidence tracked in [Phase H](Phase-H.md). Next in the manual are [Phase I](Phase-I.md) and [Phase J](Phase-J.md); final mechanical acceptance remains open.

## Future architecture

[Generation 3](../../final-build-architecture.md) means the final machine configuration, not Roadmap Stage 03. Its frozen design targets remain deferred while the original and transitional generations are documented and tested.

[Home](../Home.md) · [Current state](../project/Current-State.md) · [Roadmap](../project/Roadmap.md) · [Systems](../systems/Systems.md)

## Active Generation 3 bench — 8 October 2026

CB1, Eddy Duo and the Innomaker main camera are now received and used on the USB bench with Manta and EBB36 Gen2. See the [dated evidence](../../../hardware/bench-tests/generation-3-electronics/records/2026-10-08-usb-eddy-camera.md) and [procurement record](../../../hardware/generation-3-procurement-status.md). Partial communication/sensor/video results do not close original mechanical stages, driver/heater acceptance or final commissioning. Joint prolonged USB test → direct CAN → later CEB CAN remains the next sequence.

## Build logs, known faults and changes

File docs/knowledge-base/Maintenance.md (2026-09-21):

---
type: guide
area: documentation
status: active
updated: 2026-09-21
---

# Knowledge Base Maintenance

[Home](Home.md) · [Repository instructions](../../AGENTS.md)

The repository root is the vault. The same files are visible in Obsidian and Git; no import, duplicate vault or additional synchronization layer is required. Git changes become visible locally after they reach this working tree. Obsidian does not fetch, commit or push them automatically.

## Source ownership

| Information | Authoritative location | Knowledge-base follow-through |
| --- | --- | --- |
| Scope, progress and workstreams | [README](../../README.md), [roadmap](../ROADMAP.md), stage records | Home, Project Overview, Current State, Roadmap, Build |
| Design and decisions | [Architecture](../final-build-architecture.md), [motion architecture](../../hardware/generation-3-linear-motion.md), [smart-spool architecture](../../hardware/generation-3-smart-spool-system.md), [RASS](../../hardware/generation-3-rass.md), [toolhead architecture](../../hardware/generation-3-extrusion-toolhead.md), [enhancement candidates](../../hardware/generation-3-enhancement-candidates.md), decision evidence | Decision Log, affected Systems, Open Issues |
| Components and inventory | [Hardware](../../hardware/README.md), existing inventory, [target BOM](../../hardware/generation-3-target-bom.md) and [procurement/receiving status](../../hardware/generation-3-procurement-status.md) | Parts, affected Systems, Current State when progress changes |
| Photos | Existing archive index, manifests and dated batch records | Photos, relevant Build notes, Current State and stale source summaries |
| Illustrations | Actual editable source/export and provenance/licence record | Illustrations, relevant Systems or Build, Documentation |
| Procedures and tests | Existing manual, measurement and test records | Build, Systems, Open Issues and status properties |

Edit the owning record first. Summaries link to it; do not copy its full procedure, BOM or per-image inventory into this folder. Preserve historical snapshots and distinguish later additions. Resolve conflicting current summaries using the dated evidence; keep uncertainty visible when the evidence is insufficient.

## Properties

Use YAML frontmatter on knowledge-base notes. Scalar text properties are intentionally simple so native Properties and Bases work without community plugins.

| Property | Meaning / values |
| --- | --- |
| `type` | `dashboard`, `project`, `index`, `system`, `build-phase`, `decision-log`, `guide`; the original-design archive also uses `archive`, `catalogue`, `reference` and `part`. Use `component` or `decision` only if a dedicated note adds useful context |
| `area` | Primary topic, such as `project`, `build`, `systems`, `mechanics`, `electronics`, `firmware`, `extrusion`, `filament`, `heated-bed`, `user-interface`, `safety`, `hardware`, `evidence`, `documentation` |
| `status` | State of this note's subject; use the definitions below |
| `phase` | Roadmap identifier such as `stage-02`; omit if no single roadmap stage applies |
| `manual_stage` | Optional quoted letter `"A"`–`"J"` for the original reassembly sequence; does not replace `phase` |
| `generation` | Optional configuration context: `original`, `generation-2`, `generation-3`; omit on notes spanning generations |
| `priority` | `high`, `normal` or `low` when sequencing work is useful; not a claim from the historical source |
| `updated` | Date the note was substantively reviewed or changed, in `YYYY-MM-DD` form; not a physical inspection or decision date |

Current navigation statuses are `active` (maintained index, guide or requirements), `documented` (identified/catalogued with no implied passed test), `in-progress` (work evidenced but not closed) and `planned` (future work or completion not established).

When dedicated decision/component notes are needed, `proposed`, `under-study`, `frozen`, `implemented`, `tested`, `discarded` and `legacy` may describe their subjects. **Frozen** means a decision is constrained; **implemented** needs build evidence; **tested** needs a linked test and result. Use `complete` for a work phase only when its completion gate is recorded. Keep confidence (`CONFIRMED`/`PROBABLE`/`PENDING`) and component disposition (`REUSE`/`RESTORE`/`REPLACE`/`REDESIGN`/`ARCHIVE`) in the owning source, distinct from note workflow status.

## Update checklist

1. Update source facts, evidence/provenance and the applicable test or decision record.
2. Follow the change through the table above. Review Current State, Roadmap, Open Issues, Decision Log and affected Systems/Build/indices in the same change. When a candidate is promoted, update candidate summaries, deferred-selection lists and diagrams; preserve the original decision and link its successor.
3. Update dates and properties only where the state has changed. Preserve permanent evidence IDs and decision history.
4. Check new relative links and heading anchors. Use `[Title](relative/path.md)` with forward slashes; avoid wikilinks and absolute machine paths.
5. Reconcile affected counts/ranges in the root README, roadmap and stage summaries. Do not rewrite an old closure snapshot as if later findings had been known then.
6. Review Git changes, including new files, before committing. Mention the knowledge-base updates, or state why the change has no knowledge-base impact.

Before assigning new `KB-` or `DEC-` IDs, compare the latest published registers with pending local work. Reconcile collisions explicitly, retaining the established meaning and recording any reassignment with its old ID, new ID and date. Repair all references together and check for leftover merge markers.

Renaming a file **inside Obsidian** updates internal links with this vault's settings. Git or external-editor renames still require explicit link checks. This rule is a contributor workflow, not a background watcher.

## Shared and local Obsidian configuration

Only `.obsidian/app.json` is intended for version control. Its shared values are:

```json
{
  "useMarkdownLinks": true,
  "newLinkFormat": "relative",
  "alwaysUpdateLinks": true
}
```

These correspond to **Files and links → Use Wikilinks: off**, **New link format: Relative path to file**, and **Automatically update internal links: on**. See the [official settings reference](https://help.obsidian.md/settings) and [internal links guide](https://help.obsidian.md/links).

The root `.gitignore` ignores all other `.obsidian` content and `.trash/`: window/workspace layouts, appearance, hotkeys, bookmarks, graph preferences, property-type preferences, caches, plugin data and personal core-feature selections. If Obsidian adds personal settings to the shared `app.json`, review them individually and keep its repository policy focused. No existing repository `.gitignore` was present during setup.

Core Backlinks, Graph, Properties, Search, Bookmarks and Bases are available natively. Bases was already enabled in the local vault; its local `core-plugins.json` is not shared. In another clone, enable **Settings → Core plugins → Bases** to open [Knowledge-Base.base](Knowledge-Base.base). Its All notes, Systems and Build phases views read note properties without duplicating records. The syntax follows the [official Bases reference](https://help.obsidian.md/bases/syntax).

No community plugins are required or installed. Opening Home, bookmarking it or keeping its tab pinned is a personal preference and stays local. Use the normal Git workflow to synchronize the repository after review; do not add a second Obsidian synchronization system for this setup.

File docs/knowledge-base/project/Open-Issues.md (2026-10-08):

---
type: project
area: project
status: active
phase: stage-02
priority: high
updated: 2026-10-08
---

# Open Issues

[Home](../Home.md) · [Current State](Current-State.md) · [Decision Log](../decisions/Decision-Log.md)

This is a source-linked register of unresolved work. IDs are local knowledge-base identifiers, not GitHub issue numbers. Priorities express dependency order for this register. Close an item only after linking its resolution or test record; preserve its ID.

| ID | Priority / scope | Open item and closure evidence |
| --- | --- | --- |
| KB-002 | High / Stage 02 | Record remaining Stage H mounting/acceptance evidence, manual I–J work and the final mechanical gate. The [21 September batch](../../../photos/03-reassembly/BATCH-20260921.md) reports Stage H assembly complete and documents the geared-extruder subassembly; it does not record all manual checks. Close using results linked from the [manual](../../02-reassembly/original-reassembly-manual.md). |
| KB-003 | High / legacy extrusion | Confirm the legacy hotend revision and thermistor type; resolve the damaged heater-retaining screw/captive heater cartridge. The [roadmap](../../ROADMAP.md) explicitly leaves these unresolved. Record identification and inspection/test evidence in the existing inventory before reuse. |
| KB-004 | High / Generation 3 bed | Measure the original heated-bed PCB footprint and mounting geometry before freezing plate CAD, heater dimensions/power and related load calculations. The carriage and mirror dimensions are not substitutes. See [target BOM](../../../hardware/generation-3-target-bom.md#bed-size-rule). |
| KB-005 | Medium / Generation 3 motion | Resolve rail supplier/preload/lengths, exact X/Y 2020/2040-class profile sections and orientations, profile-to-frame brackets/adjusters, Tr8 lead and the measurement-dependent Z implementation. The Z hierarchy is already frozen: direct steel-frame mounting first, thin aluminium backing plate second, T-slot profile only if required. See [motion architecture](../../../hardware/generation-3-linear-motion.md) and [deferred selections](../../../hardware/generation-3-target-bom.md#selections-intentionally-deferred). |
| KB-006 | Medium / Generation 3 components | EBB36 Gen2 + Roto + Revo + Eddy Duo is the frozen extrusion/probing direction. EBB36 Gen2 is purchased; current Roto/Revo purchase preference is Roto Sensored + Revo 24 V / 40 W. Confirm exact Roto/Revo SKU/revision, toolplate fit, fans/ducts, Eddy mount/offsets/CAN harness/calibration, lighting, PSU integration, connectors/wire gauges and enclosure/airflow details when dependencies are known. Mean Well LRS-600-24 is the preferred final PSU model; final purchase waits for the completed load budget. See the [toolhead target](../../../hardware/generation-3-extrusion-toolhead.md) and [target BOM](../../../hardware/generation-3-target-bom.md#selections-intentionally-deferred). |
| KB-007 | Medium / imaging and interface | **Selection resolved:** main frame camera is Innomaker U30CAM-4K-S1 (Sony IMX415, USB/UVC); the former CSI-versus-USB decision is obsolete. Receipt, CB1 UVC mode query and Crowsnest/Mainsail integration are now tested. Remaining closure work is sustained concurrent operation, higher-mode testing and final mount/framing/focus. Initial USB disruption cause is unproven; later reboot/cold start worked. The optional nozzle camera remains a separate possible upgrade. See the [main-camera record](../../../hardware/generation-3-main-camera.md). |
| KB-008 | Medium / illustrations | No standalone project illustration assets have been established in this checkout; existing inline design diagrams are indexed separately. Imported period text references images that are not bundled. Track source/licence and separate future diagrams from photo evidence; see [Illustrations](../indexes/Illustrations.md). |
| KB-009 | Medium / archaeology documentation | Expand the detailed per-image table for photographs 073–080 without assigning retrospective provenance. The gap is recorded by the [detailed inventory](../../00-archaeology/05-detailed-photo-inventory.md). |
| KB-010 | Medium / Generation 3 smart spools | Resolve reader/antenna, tag schema, load cell/holder, controller, service/database and UI details; validate real-tag decoders and profile mappings before claiming support. Follow the [smart-spool open decisions](../../../hardware/generation-3-smart-spool-system.md#open-component-level-decisions), preserving manual fallback and stable weighing as the inventory reference. |
| KB-011 | High / Revival Intelligence & Diagnostics | Work through the practical [RID candidate backlog](../../../hardware/generation-3-enhancement-candidates.md) under the [RID subsystem rules](../../../hardware/generation-3-revival-intelligence-diagnostics.md): prototype software-only candidates first, then minimal-hardware/high-impact candidates one by one. Record benefit, complexity, dependencies, false positives/negatives, autonomy, failure modes, safety and measured results before promote/defer/reject decisions. The M01–M15 Moonshots are explicitly outside the normal implementation queue and remain production-score 1/5 research ideas unless a later decision changes that. Hardware emergency-stop topology remains an open final-safety design item. |
| KB-012 | Medium / Generation 3 RASS | Prototype the available 28BYJ-48 5 V + ULN2003 as the spool-drive assist, then design and validate the production **custom Klipper-compatible RASS CAN Node** for the CEB backbone: MCU/transceiver/protection/termination, feeder and spool-drive motor drivers, feeder geometry/encoder, buffer-dancer mechanism and sensing, spool-rotation feedback, PTFE routing, fallback/freewheel design and control calibration. The released board must run unmodified upstream Klipper MCU firmware and expose every remaining electrically usable MCU pin after production allocation, with a complete pin/resource ledger documenting alternate SPI/I2C/UART/ADC/GPIO/PWM capabilities and justified exceptions. Preserve the toolhead direct-drive extruder as master and keep the full spool support inside the calibrated load-cell path. High-level RFID/NFC decoding remains separate from deterministic RASS motor control. See [RASS open decisions](../../../hardware/generation-3-rass.md#open-component-level-decisions) and [custom-node rules](../../../hardware/generation-3-custom-can-node-design-rules.md). |
| KB-013 | Medium / Generation 3 procurement/bench test | Receive, photograph and bench-test the purchased Manta M8P V2.0, EBB36 Gen2 kit and 6× TMC2209 V1.3 while warranty/return windows are open. The [versioned bench-test pack](../../../hardware/bench-tests/generation-3-electronics/README.md) is now prepared, including Raspberry Pi 2 host setup, six-driver isolation, eight Manta-socket coverage, EBB36 USB checks and a two-node CAN test. CB1 is now the active temporary host; partial USB MCU/sensor/camera results are recorded in the [8 October session](../../../hardware/bench-tests/generation-3-electronics/records/2026-10-08-usb-eddy-camera.md). Joint 30-minute acquisition, full-board motor/I/O tests, direct CAN and later CEB CAN remain pending. CB2 remains pending. Close only after reviewed PASS evidence is recorded in the [procurement status](../../../hardware/generation-3-procurement-status.md). |
| KB-014 | High / original printable parts | Confirm exact design-to-part matches, remaining accessory coverage and source attribution; see [coverage details](#kb-014--exact-original-printable-part-coverage). |

| KB-015 | Medium / Generation 3 Bed Node | Design and validate the custom Revival Bed Node PCB: CAN-primary / USB-service Klipper MCU fixed to the rear cross-member and connected through CEB V1.0; CAN transceiver/protection and selectable 120-ohm termination; USB-C first-flash/recovery/alternate-runtime path; remote moving-bed IMU; local chassis IMU; remote frame-top IMU interface; primary/secondary temperature channels; heater voltage/current/PCB-temperature telemetry; 24 V RGB status-light outputs; local heater MOSFET/power stage; connectors/strain relief; boot/recovery access and auxiliary expansion. The released board must run unmodified upstream Klipper MCU firmware and expose every remaining electrically usable MCU pin after production allocation, with a complete pin/resource ledger documenting alternate SPI/I2C/UART/ADC/GPIO/PWM capabilities and justified exceptions. Initial conventional bed wiring remains valid until this PCB passes bench and thermal testing. Close with schematic/PCB review, CAN/USB firmware/config, resource-ledger review, current/thermal validation and documented fail-safe tests. See [Bed Node architecture](../../../hardware/generation-3-bed-node.md) and [custom-node rules](../../../hardware/generation-3-custom-can-node-design-rules.md). |

| KB-016 | Medium / RID software architecture | Define the provider-neutral RID software interfaces and data contracts: mechanical/thermal-electrical/extrusion/vision domain models, sensor-fusion evidence format, machine-baseline storage, severity/confidence model and optional LLM provider abstraction. Core RID must run with LLM disabled; local-network and external providers are optional. Close with a versioned schema/API and one end-to-end prototype. See [RID architecture](../../../hardware/generation-3-revival-intelligence-diagnostics.md). |

| KB-017 | High / Generation 3 power distribution | Release the [separate PSU and XT60E/XT30(2+2) architecture](../../../hardware/generation-3-power-distribution.md): confirm mains enclosure compliance, inlet/switch/PE arrangement, safe connector gender, Manta VBB/HV and controller supply isolation, actual manufacturer footprints, one-source EBB/CAN power injection, branch fuse ratings, conductor sections and heater thermal cutoff. Close with verified drawings, calculations, inspection and documented fault/thermal tests. |

Further commissioning, spare-electronics evaluation and legacy-filament qualification remain planned work in the [roadmap](../../ROADMAP.md), [spares record](../../00-archaeology/06-motion-electronics-spares.md) and [filament inventory](../../01-filaments/01-inventory.md). Their presence in inventory does not establish a passing test.

## KB-014 — Exact original printable-part coverage

**High / Stage 02.** The [historical design sets](../../../printed-parts/original-designs/Original-Printed-Parts.md) are now archived, including the leading 9/47 gear-pair candidate. The supplier and precise kit revision remain unknown. Confirm gear teeth/bore/spacing and each selected part's measured interfaces; identify the remaining mechanical endstop mounts, hotend clamp/duct and loose accessory revisions. Close with source-to-physical-part mapping and fit evidence, not download counts. Preserve source notices; individual attribution/license details for the Clone Wars V2/Extras files also remain to be resolved as recorded in [provenance](../../../printed-parts/original-designs/Provenance.md).

The archive-coverage item previously duplicated the procurement ID KB-013. On 21 September 2026 it was reassigned to KB-014; KB-013 continues to track purchased electronics and bench testing.

## Resolved items

| ID | Resolution date | Closure evidence |
| --- | --- | --- |
| KB-001 | 2026-09-21 | Reconciled the [archaeology photo README](../../../photos/00-archaeology/README.md) with the [catalogue](../../00-archaeology/02-photo-catalogue.md), [spare-box provenance](../../00-archaeology/06-motion-electronics-spares.md) and 89 repository JPEGs: 80 historical baseline images plus nine later sanitized spare-box photographs. Image files and permanent IDs are unchanged. |

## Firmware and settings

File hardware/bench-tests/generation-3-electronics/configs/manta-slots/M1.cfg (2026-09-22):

# Manta M8P V2.0 — socket M1
[manual_stepper m1]
step_pin: PE6
dir_pin: PE5
enable_pin: !PC14
microsteps: 16
rotation_distance: 40
velocity: 2
accel: 5

[tmc2209 manual_stepper m1]
uart_pin: PC13
run_current: 0.30
sense_resistor: 0.110
interpolate: False
stealthchop_threshold: 0

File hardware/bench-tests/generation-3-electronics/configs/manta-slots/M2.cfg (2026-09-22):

# Manta M8P V2.0 — socket M2
[manual_stepper m2]
step_pin: PE2
dir_pin: PE1
enable_pin: !PE4
microsteps: 16
rotation_distance: 40
velocity: 2
accel: 5

[tmc2209 manual_stepper m2]
uart_pin: PE3
run_current: 0.30
sense_resistor: 0.110
interpolate: False
stealthchop_threshold: 0

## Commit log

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2026-09-12 docs: turn archaeology folder into documented project stage
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2026-09-13 photos: add historical cable chain prototypes (ARQ 073–076)
2026-09-13 photos: remove sensitive metadata from all archived images
    Sanitize all 87 JPEGs, retaining existing capture date/time fields,
    orientation, and ICC color profiles. Remove GPS, device/software
    identifiers, proprietary blocks, thumbnails, and auxiliary payloads.
    Verify unchanged JPEG codestreams, oriented decoded pixels, and ICC
    profiles; do not invent capture timestamps for files without them.
    Earlier commits still require a separate history cleanup.
2026-09-13 Add Stage 01 teardown photo baseline
    [manifest.csv]
2026-09-13 Add final teardown inventory photo batch
    [inventory-20260913.csv]
2026-09-13 Add cleaned component inventory photos
    [manifest.csv]
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2026-09-13 Complete component inventory manifests through TD-228
    [manifest.csv]
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2026-09-13 Add original Prusa i3 Stage 02 reassembly manual
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2026-09-13 Make frame camera interface open and add nozzle-camera upgrade
2026-09-13 Document Stage 02 colour and temporary print policy
2026-09-15 Add Stage 02 reassembly photo archive
    [duplicate-report.csv, manifest.csv]
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2026-09-15 Add Stage 02 reassembly photos for 2026-09-15
    [manifest.csv]
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2026-09-16 Add Stage 02 reassembly photos for stages B through G
    [BATCH-20260916-classification.csv, manifest.csv]
2026-09-16 Add smart spool identification and weighing to Generation 3 BOM
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2026-09-19 Add RASS active spool system to Generation 3 BOM
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2026-09-20 Add preferred Roto Revo toolhead to Generation 3 BOM
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2026-09-20 Sync Current State with preferred Roto Revo toolhead
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2026-09-20 Freeze Roto Revo Eddy Generation 3 toolhead stack
2026-09-20 Add Eddy Duo to frozen Generation 3 toolhead target
2026-09-20 Sync Obsidian extrusion note with frozen Eddy toolhead
2026-09-20 Sync Obsidian heated bed note with Eddy Duo
2026-09-20 Sync Current State with frozen Roto Revo Eddy stack
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2026-09-20 Sync BOM with purchased electronics and toolhead procurement choices
2026-09-20 Document exact frozen toolhead stack and purchase preference
2026-09-20 Record purchased Manta drivers and interim host testing in final architecture
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2026-09-20 Sync Extrusion knowledge note with exact toolhead purchase status
2026-09-20 Sync Extrusion note with exact toolhead purchase status
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2026-09-21 Add Stage 02 reassembly photos for phase H
    [BATCH-20260921-classification.csv, bearing-guide.scad, bearing.scad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]
2026-09-21 Reconcile Obsidian vault and index Stage H evidence
    Synchronize project status and photo records for 116 reassembly images, resolve conflicting decision IDs, and align architecture summaries with frozen choices. Preserve original evidence and printable design files.
    [manifest.csv]
2026-09-22 Add Generation 3 electronics bench-test pack
    Version the Manta M8P V2.0, six TMC2209 V1.3 and EBB36 Gen2 acceptance workflow, conservative Klipper bench templates, CAN checks and result records. Link the pack from procurement and Obsidian knowl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
    [M1.cfg, M2.cfg, M3.cfg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]
2026-09-22 Fix EBB36 bench motor disable command
2026-09-23 Import BIGTREETECH vendor reference documentation
    [generic-bigtreetech-manta-m8p-V2_0.cfg, sample-bigtreetech-ebb36-gen2-v1.0.cfg]
2026-09-23 Document 28BYJ-48 prototype candidate for RASS spool drive
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2026-09-23 Sync Obsidian filament system with RASS spool-drive prototype
2026-09-23 Update RASS open issue with 28BYJ-48 prototype test
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2026-09-29 Add official Manta M8P and EBB adapter STEP references
    [BIGTREETECH MANTA M8P V2.0.step, EBB36&42 GEN2 Adapter V1.0.step]
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2026-09-30 Document custom Generation 3 Revival Bed Node architecture
2026-09-30 Add staged Revival Bed Node architecture to Generation 3 BOM
2026-09-30 Integrate custom Bed Node into final build architecture
2026-09-30 Document staged Bed Node plan in Obsidian heated-bed note
2026-09-30 Sync Electronics knowledge note with Revival Bed Node
2026-09-30 Document Klipper integration model for Revival Bed Node
2026-09-30 Add Revival Bed Node design issue to Obsidian
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2026-09-30 Refine Bed Node placement, remote IMU and Klipper flashing plan
2026-09-30 Update final architecture for fixed rear Bed Node
2026-09-30 Sync heated-bed note with fixed Bed Node placement
2026-09-30 Sync electronics note with fixed Bed Node and remote IMU
2026-09-30 Add custom Bed Node Klipper build and flashing workflow
2026-09-30 Refine Bed Node open issue for fixed placement and firmware recovery
2026-09-30 Record fixed rear Bed Node and remote IMU decision
2026-09-30 Expand Bed Node with structural IMUs RGB and telemetry
2026-09-30 Add Bed Node IMUs RGB and telemetry to target BOM
2026-09-30 Add Bed Node sensor fusion inputs to RID architecture
2026-09-30 Reflect expanded Bed Node role in final architecture
2026-09-30 Sync heated-bed note with expanded Bed Node sensing
2026-09-30 Sync electronics note with Bed Node IMUs and RGB
2026-09-30 Expand Bed Node implementation issue
2026-09-30 Record expanded Bed Node sensing and RGB decision
2026-09-30 Document RID sensor fusion and external LLM architecture
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2026-10-03 Align Generation 3 BOM with CAN-primary Bed Node
2026-10-03 Route Revival Bed Node through Generation 3 CAN backbone
2026-10-03 Update heated-bed knowledge base for CAN Bed Node
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2026-10-03 Update Bed Node firmware model for CAN-primary transport
2026-10-03 Update Bed Node open issue for CAN and USB
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2026-10-03 Add Bed Node branch to Generation 3 CAN procurement topology
2026-10-03 Move RASS production controller to custom Klipper CAN node
2026-10-03 Add custom RASS CAN node to Generation 3 BOM
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2026-10-03 Freeze upstream Klipper firmware and expansion reserve for Bed Node
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2026-10-03 Replace minimum expansion reserve with full unused-pin exposure
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2026-10-06 Replace obsolete CSI-first camera architecture
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2026-10-06 Resolve main camera selection in open issues
2026-10-08 Document Gen3 PSU enclosure XT60 outputs and XT30 CAN power harness architecture
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2026-10-08 Document October 8 USB Eddy and camera bench and synchronize Obsidian
    Record tested short-cable colour correction, MCU identities and observed firmware, direct-USB frequency baseline, camera disruption/recovery, Crowsnest proxy and Mainsail video, warm/cold starts and pending USB/direct-CAN/CEB gates.
    Update canonical bench, camera and procurement records plus Home, Current State, Open Issues, Roadmap, Electronics, Firmware, User Interface, Documentation, Parts and Build notes. Preserve full-board commissioning boundaries and distinguish host-only evidence from uploaded records.
2026-10-16 docs: record CM4 and CEB orders and provisional Raspberry Pi OS Lite choice
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
